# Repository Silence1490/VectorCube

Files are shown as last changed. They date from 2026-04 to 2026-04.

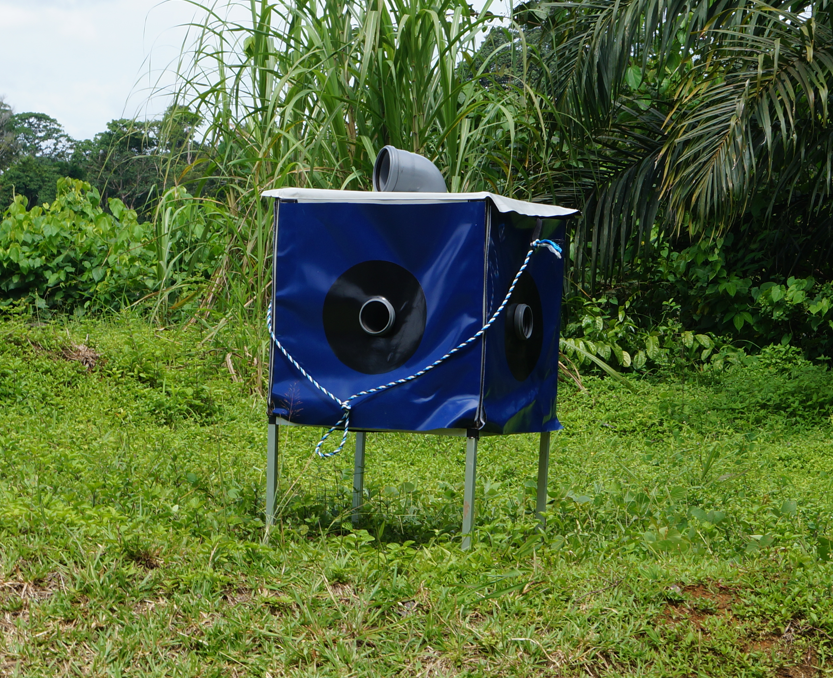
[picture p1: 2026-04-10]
images/real_build/VectorCube_fully_assembled.png

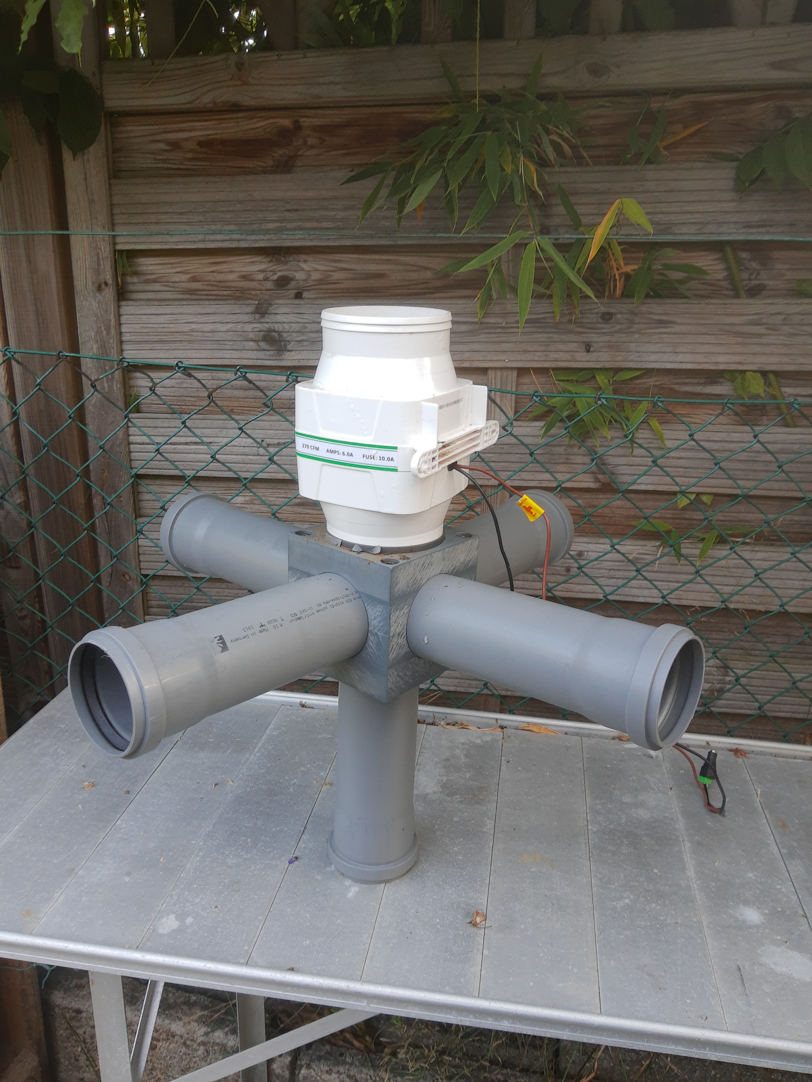
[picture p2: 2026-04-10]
images/real_build/vectorcube_interior_system_assembled.jpg

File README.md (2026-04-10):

# VectorCube

Open-source repository containing the raw data, CAD files, and fully reproducible analysis for the VectorCube project. Includes all materials required to rebuild the VectorCube trap, reproduce the statistical analyses (GLMM/GAMM), and regenerate all tables and figures from the associated scientific publication.

## VectorCube – Data, Construction Files & Reproducible Analysis

This repository contains the complete dataset, CAD construction files, and analysis scripts used in the VectorCube study. It enables full reconstruction of the VectorCube trap and complete reproducibility of all statistical analyses and results from the associated scientific publication.

## Contents
Raw and processed data
CAD files and building instructions for the VectorCube
R scripts for GLMM/GAMM analyses
Reproducible environment (renv)
Generated figures and tables

All tables, figures, and models from the manuscript can be regenerated directly from the scripts provided here.

 ## VectorCube Construction (Condensed)

The VectorCube is a modular airflow-based insect trap consisting of a central airflow distributor, an inline duct fan, a pipe-based intake system, and an aluminium frame enclosed by a tarpaulin cover.

### Core components
Interior airflow block (milled or 3D printed),
Inline duct fan (100–125 mm diameter, ~270 CFM),
DN 75 pipes with push-fit sockets (European standard),
20 × 20 mm aluminium square tubing with corner connectors,
Tarpaulin cover with hook-and-loop fasteners,
Optional capture chamber (DN 75 to 50 reducer + Falcon tube)

### Assembly overview
Prepare interior block
Manufacture or print the airflow distributor and ensure smooth internal channels.
Mount fan
Attach the inline duct fan to the top of the block (use adapter for milled version).
The ribbed fan outlet may need to be sanded down to achieve an airtight fit.
Install pipes
Insert four horizontal and one vertical DN 75 pipes into the block. Ensure tight, airtight connections.
Assemble frame
Construct the frame from 20 × 20 mm aluminium square tubing and position the airflow system centrally.
Align openings
Ensure the intake openings in the outer cover align with the pipe ends.
Install cover
Enclose the frame with the custom tarpaulin cover. Close the lid using hook-and-loop fasteners.
Colored foils can be attached externally for visual attraction.
Final setup
Connect the fan to a power supply (e.g., 12V DC) and verify correct airflow direction (upward suction).
Additional notes
An 87° DN 110 pipe elbow can be installed at the fan outlet to prevent rain from entering the system.
CO₂ sources (e.g., yeast fermentation, dry ice, or bottled CO₂) can be added to enhance attraction.
The system is modular and can be adapted with different capture mechanisms.
Full construction manual

For detailed instructions, see:

/docs/VectorCube_Construction_Manual.docx

## Large CAD files

Due to file size limitations, full-resolution STL files are available via Zenodo:

https://doi.org/10.5281/zenodo.19496635

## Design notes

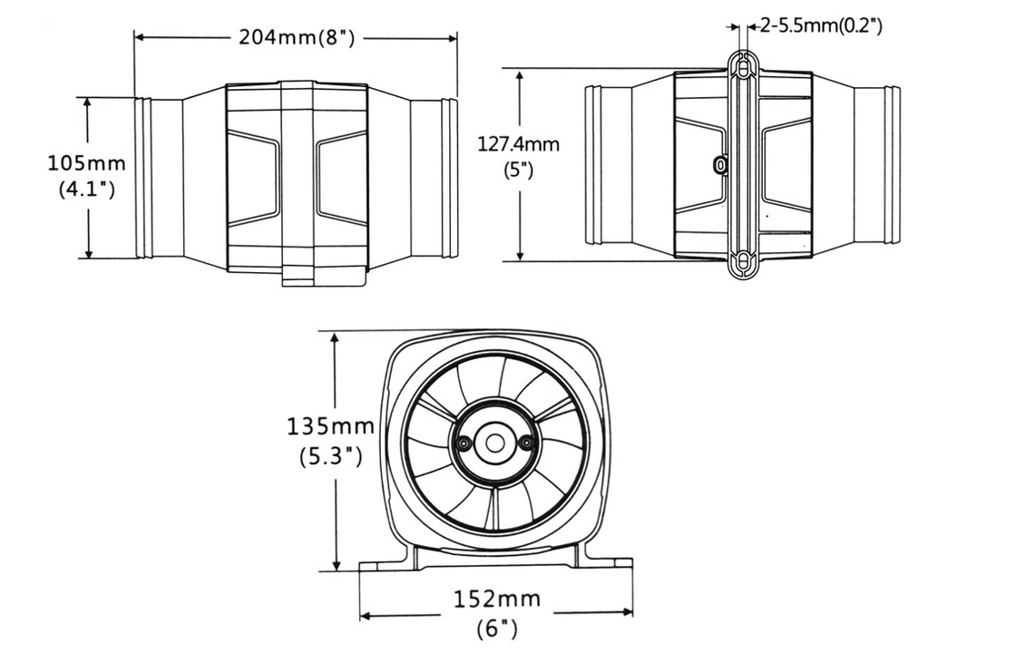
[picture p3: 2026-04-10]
images/drawings/inline_duct_fan_spec.png

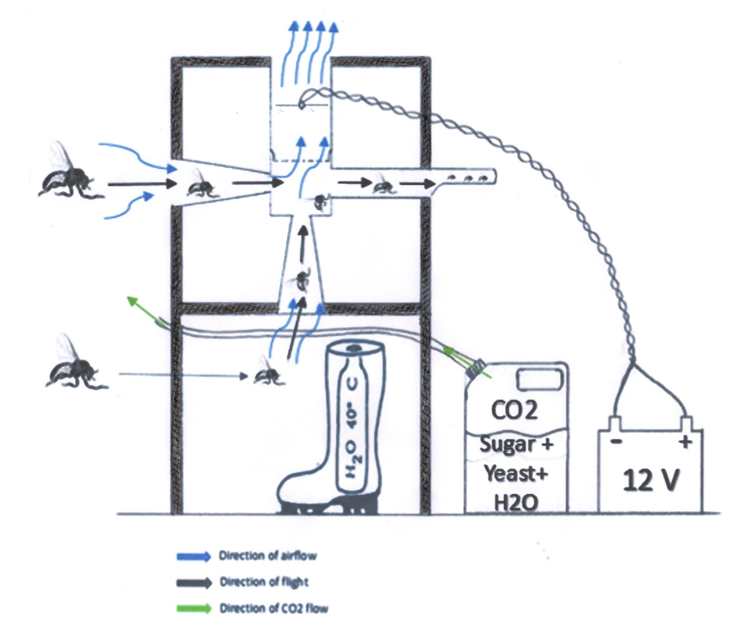
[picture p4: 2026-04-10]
images/schematic/VectorCube_schematic.png

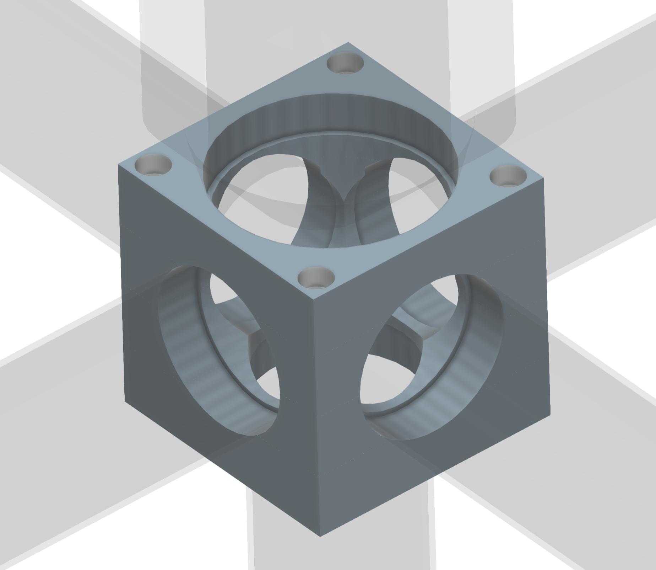
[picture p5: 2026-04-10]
images/schematic/VectorCube_interior_block_milled.png

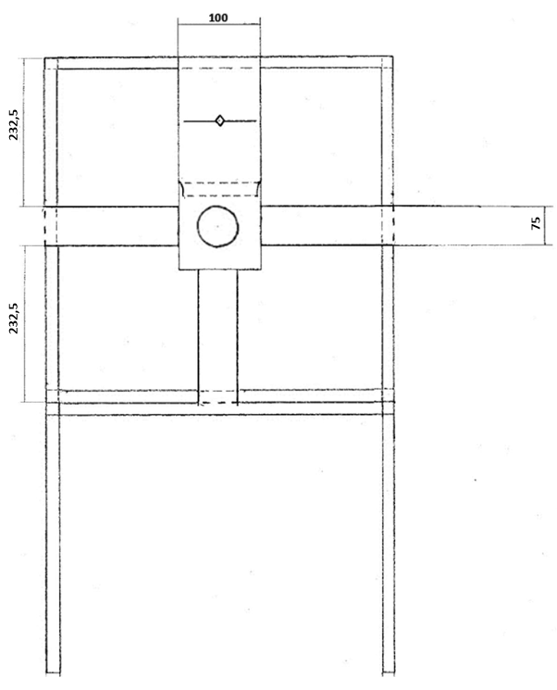
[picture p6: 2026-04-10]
images/drawings/VectorCube_frame_and_interior_front.png

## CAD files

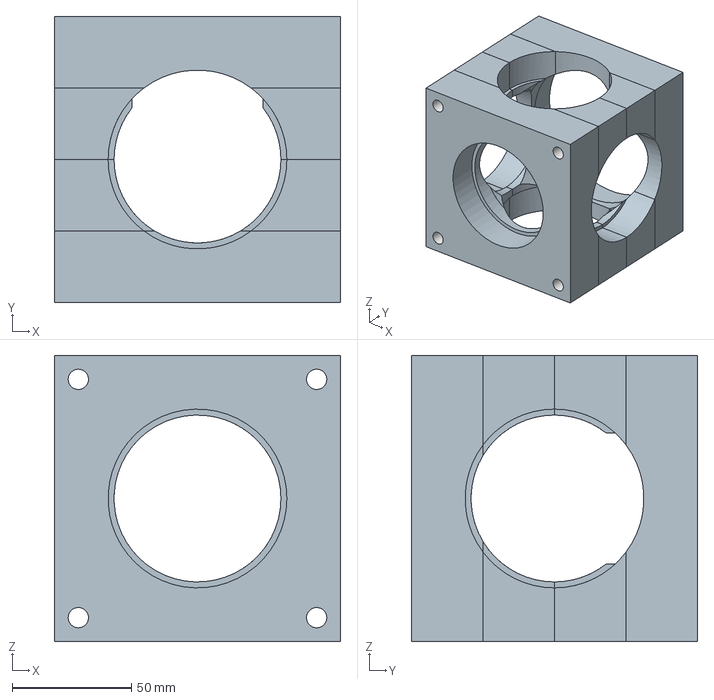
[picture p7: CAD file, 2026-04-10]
cad/Milled Interior Block/block.stp
120.0 x 120.0 x 120.0 mm

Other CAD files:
cad/Milled Interior Block/Block.ipt
cad/Milled Interior Block/assembly/Baugruppe Fliegenfalle.iam
cad/Milled Interior Block/components/Lüfter.ipt
cad/Milled Interior Block/components/Rohr.ipt

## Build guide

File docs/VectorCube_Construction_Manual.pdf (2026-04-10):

VectorCube Construction Manual

## Overview

The VectorCube is a modular active (airflow-based) insect trap designed to attract and capture blood-searching insects using controlled airflow, visual attraction, and CO₂ baiting. The system consists of a central airflow distributor, an inline duct fan, a pipe-based intake structure, and a supporting frame.

Air is drawn through four horizontal and one vertical intake arms into a central block and then pulled upward by a fan, creating directional flow that guides insects into the trap.

## Functional Principle

Airflow generation

A central fan generates suction, drawing air through four horizontal and one vertical intake pipes.

Directional guidance

The interior block distributes airflow evenly, ensuring consistent suction from all directions.

Vector attraction

A CO₂ source (e.g., yeast fermentation, bottled CO₂, or dry ice) can be used to attract insects and guide them into the airflow. Additionally, the colored tarpaulin provides visual attraction.

Vector capture

Different capture methods can be implemented:

### 1. A capture net placed after the fan (captures are damaged) 2. A capture chamber positioned before the fan (under development)

3. A mesh placed at the fan intake combined with a capture chamber connected to one of the horizontal intake pipes

## Components

### 1. Interior Airflow Block

Files:
VectorCube_interior_block_milled.png
VectorCube_interior_block_printed.png

Central cube that connects all pipes and the fan. Contains internal channels to distribute airflow. Can be manufactured via CNC milling or 3D printing. Ensure smooth internal geometry and airtight pipe interfaces.

### 2. Fan Adapter (only for milled internal block)

File:
vectorcube_fan_mount_detail_milled.jpg

Milled connector between fan and interior block. Optionally, duct tape can be applied around the fan can replace adapter. Ensures airtight transition and proper alignment. The ridges on the fan housing were sanded down to ensure a smooth, airtight fit with the adapter.

### 3. Pipe System

Files:
vectorcube_interior_system_assembled.jpg vectorcube_interior_system_assembled2.png

Four horizontal and one vertical intake pipes.
Material: DN 75 wastewater pipes with integrated push-fit sockets (European standard).

### 4. Inline Duct Fan

File:
inline_duct_fan_spec.png

Diameter: 100–125 mm
Airflow: approx. 270 CFM
Power: typically 12V

Generates the suction force driving the airflow through the system. Can be used with an adjustable power supply for airflow adjustment.
An 87° DN 110 pipe elbow was installed at the outlet to prevent rain from entering the system.

### 5. Frame Structure

Files:
VectorCube_frame_front.png VectorCube_frame_and_interior_front.png

Inner support structure defining the geometry of the trap and holding airflow system in place.
Material: 20 × 20 mm aluminium square tubing with compatible plastic corner connectors.

### 6. Openings / Inlets

File:
VectorCube_openings_top.png

Precisely positioned entry points aligned with intake pipes to control how insects enter the system.

### 7. Capture Chamber

Components:
- 75 mm to 50 mm reducer (HT pipe)
- 50 ml Falcon tube

The capture chamber can be connected to one of the horizontal intake pipes. The Falcon tube serves as a removable collection container.

## Cover

The frame is enclosed by a custom-made tarpaulin cover. The enclosure includes a lid that can be closed using hook-and-loop fasteners. Colored foils can be attached to the exterior using the same fastening system to provide visual attraction.

The cover is equipped with two attachment loops, allowing a rope or strap to be fastened so the device can be carried over the shoulder or suspended during operation.

## Assembly Instructions

### 1. Prepare Interior Block: Manufacture or 3D print the airflow block. Ensure internal

channels are clean and unobstructed.

### 2. Attach Fan: Mount the fan on top of the block (use adapter if milled). Ensure airtight

connection.
3. Install Pipes: Insert horizontal and vertical pipes. Ensure tight fits and seal if necessary.
4. Mount Fan: Verify airflow direction (must pull air upward).
5. Assemble Frame: Construct frame and position system centrally.

### 6. Align Openings: Ensure intake openings align with pipe ends an push them through

slightly for stabilisation.
7. Final Assembly: Secure all components and check stability.

## Electrical Setup

Connect the fan to a suitable power supply (e.g., 12V DC). Ensure correct polarity. Optional: switch or speed controller.

## Optional CO₂ System

Use a mixture of sugar, yeast, and water. Route CO₂ output into the airflow region and position near intake.

## Final Checklist

- All connections are airtight
- Fan airflow direction is correct
- Pipes are securely mounted
- Frame is stable
- No internal blockages
- Electrical connections are safe
